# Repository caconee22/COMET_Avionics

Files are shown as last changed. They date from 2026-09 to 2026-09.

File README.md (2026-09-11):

# COMET_Avionics

COMET rocket avionics hardware project archive.

This repository replaces the previous `COMET_ROK_2` repository with the full
COMET avionics workspace layout.

## Structure

- `ROK2025/`: ROK2-era module board and reference files.
- `ROK2026/`: Current ROK2026 KiCad projects, shared libraries, and revisions.
- `ROK2026/ROK_3/`: ROK3 small-form-factor and SMD-chip test board.
- `ROK2026/ROK_4/`: ROK4 power-design research test board.
- `ROK2026/Away_1/`: Current active avionics candidate version under development.

## Project History

- `ROK2025/COMET_ROK_2`: First ROK2 circuit and module board. It was not used
  because of software development staffing issues.
- `ROK2026/ROK_3`: Miniaturized ROK3 version with SMD chips. It was not used
  because of power-section issues, but it may still be recoverable and remains
  a test version.
- `ROK2026/ROK_4`: A further test version focused on power-section design. It
  is a research version for a small buck-converter power design.
- `ROK2026/Away_1`: The avionics version candidate intended for actual use. It
  is currently under development.

## Avionics Design Intent

This design intent applies to the whole COMET avionics board family.

## 설계 목적

COMET_Avionics의 목적은 단순한 데이터 로거가 아니라, 로켓 비행 중 필요한
항공전자 기능을 안정적으로 수행하는 것이다.

가장 중요한 기능은 최고점 판단, 지연 사출 판단, 그리고 실제 사출 작동이다.
로그 저장, 통신, GPS 전송, LED, 부저, 콘솔 출력은 모두 보조 기능이며,
이 기능들이 사출 판단과 작동을 막아서는 안 된다.

## 우선순위 규약

1. 사출 판단과 사출 작동을 최우선으로 둔다.
2. SD카드 기록, LoRa, MQTT, Wi-Fi/LTE, GPS 텔레메트리, LED, 부저, 콘솔은
   사출 경로를 블로킹하지 않아야 한다.
3. 센서 감시는 100Hz 이상을 기본 목표로 한다.
4. 저장과 통신은 큐나 별도 작업으로 분리해 지연이 생겨도 비행 판단에 영향을
   주지 않게 한다.
5. 실제 비행 적용 전에는 회로, 펌웨어, 전원부, 사출부를 별도로 검증해야 한다.

## 센서와 비행 판단

기본 설계 방향은 압력 센서, IMU, 배터리 전압, 사출 감지, GPS 최신값을 함께
다루는 것이다.

`Away_1`의 메인 IMU는 STMicroelectronics `LSM6DSO32XTR`를 채택한다.
이 센서는 3축 가속도, 3축 자이로, 온도 센서를 포함하며, 가속도는 최대
±32g, 자이로는 최대 ±2000dps 범위를 기준으로 사용할 수 있다.

비행 중에는 발사 감지, 최고점 판단, 지연 사출, 착지 판단, 회수 모드 진입을
이벤트로 남긴다. 고도, 필터링된 속도, 가속도 크기, 발사/최고점 판단 점수,
GPS 속도와 방향처럼 후처리가 가능한 값은 가능한 한 뷰어나 분석 도구에서
계산한다.

## 어포지 판단 예비 기준

어포지 판단은 센서 하나만으로 결정하지 않고, 기압 고도, IMU 상태, 시간 조건을
함께 보는 상태머신으로 구성한다. 초기 로켓은 발사 실패, 중간 고도 이후 뒤집힘,
상하 반전, 과격한 회전, 불안정 비행이 생길 수 있으므로 정상 비행만 가정하지
않는다.

기본 상태 흐름은 다음을 기준으로 한다.

1. `PAD`: 발사 전 대기 상태.
2. `LAUNCHED`: 발사 감지 후 상승 시작 상태.
3. `COAST_NORMAL`: 정상 상승/관성 비행으로 판단되는 상태.
4. `UNSTABLE_FLIGHT`: 뒤집힘, 과격한 회전, 고도 상승 이상 등 비정상 비행 상태.
5. `APOGEE_DETECTED`: 어포지 또는 하강 시작이 확인된 상태.
6. `FAILSAFE_DEPLOY`: 센서 이상이나 비정상 비행으로 백업 사출이 필요한 상태.
7. `RECOVERY`: 사출 이후 회수 상태.

정상 어포지 판단은 다음 조건을 함께 본다.

- 발사 감지가 완료되어 있을 것.
- 발사 후 최소 사출 금지 시간이 지났을 것.
- 필터링된 기압 고도 기준 최고 고도를 추적할 것.
- 현재 고도가 최고 고도보다 일정량 이상 낮아질 것.
- 필터링된 수직 속도가 음수 방향일 것.
- 위 조건이 짧은 시간 동안 지속될 것.

초기 기준값은 다음 범위에서 시험하며 조정한다.

- 최소 사출 금지 시간: 발사 후 1~2초.
- 고도 하락 판단: 최고 고도 대비 2~5m 하락.
- 하강 지속 시간: 200~500ms.
- 백업 사출 시간: 예상 어포지 이후를 기준으로 별도 시험값 설정.

비정상 비행 판단은 다음 상황을 감지하는 방향으로 둔다.

- 자이로 회전율이 일정 시간 이상 매우 큰 상태.
- 가속도 방향이 계속 급격하게 바뀌는 상태.
- 발사 후 고도 상승이 거의 없거나 예상보다 빨리 멈추는 상태.
- 고도 상승 후 불규칙한 정체와 하락이 반복되는 상태.
- IMU 축 기준 위아래 판단이 신뢰하기 어려운 상태.

비정상 비행 상태에서는 IMU 적분 고도나 자세 기준 판단에 의존하지 않는다.
기압 고도 변화, 시간 조건, 회전 이상 감지를 우선 사용하고, 필요하면 정상
어포지보다 보수적인 백업 사출 조건으로 전환한다.

개념적인 판단식은 다음과 같다.

```text
if launched and time_since_launch > min_deploy_time:
    if altitude_peak - altitude_filtered > altitude_drop_threshold
       and vertical_velocity_filtered < 0
       and falling_duration > falling_hold_time:
        apogee_detected = true

    if unstable_flight and altitude_not_increasing:
        failsafe_deploy = true

    if time_since_launch > max_flight_time:
        failsafe_deploy = true
```

이 기준은 비행 검증 완료값이 아니라 초기 개발용 예비 기준이다. 실제 임계값은
기체 질량, 모터 추력 곡선, 벤트홀 설계, 지상 시험, 저고도 시험 결과를 보고
조정한다.

## 로그 규약

로그는 텍스트보다 바이너리 형식을 우선한다.

- `LOG`: 고정 길이 센서 샘플
- `EVENT`: 발사, 최고점, 사출, 착지, 전압 변화, SD 오류, 파일 회전, 통신 상태,
  GPS fix/loss, 회수 모드 진입 같은 이벤트 기록

`LOG`에는 시간 코드, 시퀀스 번호, 상태 플래그, 압력, 온도, IMU 가속도/자이로,
최신 GPS 위도/경도/고도, GPS 플래그, 배터리 전압, 사출 센서 상태 같은
raw/minimal 값을 저장하는 방향으로 둔다.

## 로그 동작 흐름

패드 대기 또는 armed 상태에서는 최근 약 3초 분량의 100Hz RAM prebuffer를
유지한다. 평상시 저장은 10Hz 정도로 제한할 수 있다.

발사가 감지되면 발사 직전 prebuffer와 발사 이후 데이터를 100Hz로 저장한다.
최고점/사출 이후 하강 구간은 짧은 시간 단위 파일로 분리하는 방향을 둔다.

착지가 10초 이상 안정적으로 확인되면 고속 로그를 닫고, 회수/저전력 모드로
전환한다. 이 상태에서는 1Hz 수준으로 로그를 줄이고 GPS 위치를 LoRa와 MQTT로
전송하는 것을 목표로 한다.

## 통신과 회수

LoRa 433MHz는 지상국과 회수용 통신을 위한 기본 방향으로 둔다.
MQTT는 온보드 Wi-Fi/LTE 라우터를 통한 원격 모니터링 또는 회수 보조 용도로
사용할 수 있다.

통신 실패는 비행 판단 실패로 이어지면 안 된다. 통신은 가능한 경우 보내고,
안 되는 경우에는 로그와 사출 판단이 계속 살아 있어야 한다.

## 검증 기준

이 문서는 COMET_Avionics 전체 보드에 적용되는 설계 의도와 개발 규약이다.
각 보드는 실제 비행 적용 전 회로, 펌웨어, 전원부, 사출부를 별도로 검증해야
하며, README에 적힌 내용만으로 비행 검증 완료를 의미하지 않는다.

Temporary extraction/work folders such as `tmp/` and `tmp_pdf_kmg/` are not
tracked.

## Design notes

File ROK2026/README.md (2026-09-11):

# ROK2026

COMET ROK 2026 hardware project workspace.

## Projects

- `ROK_3`: Miniaturized ROK3 SMD-chip test board.
- `ROK_4`: ROK4 power-section design and small buck-converter research board.
- `Away_1`: Active avionics candidate version under development.

## Board Status

- `ROK_3`: Small-form-factor version using SMD chips. It was not used because
  of power-section issues, but it may still be recoverable and remains a test
  version.
- `ROK_4`: Further test version for power-section design. It is a research
  board for the small buck-converter power design.
- `Away_1`: The candidate avionics version intended for actual use. This is the
  current development target.

## Away_1

`Away_1` is the active candidate for the real avionics version.
It is currently under development.

The avionics design intent and development rules apply to the whole board
family and are documented in the root `README.md`.

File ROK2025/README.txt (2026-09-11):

ROKv2.xlsx 에 모든 설명이 있으며 두 시트를 참조하시오
ROK2.zip 파일이 PCB 의 데이터 원본 파일이며 KICAD 로 편집할수있습니다
GB.zip 에 거버파일이 있으며 이를 이요해 같은 PCB 를 생산할수있습니다
C3_ROK2.zip 의 테스트를 위해 구동하던 약간의 예제 코드가 있으며 이는 구동을 위한것이아닌 개발환경 예시를 위함입니다 코딩은 직접 해야합니다
C3_ROK.step 은 모델 파일이며 설개참조를 위해 있습니다

2026/01/20 스마트융합공학과 융합로봇전공 이학현
lhh060508@gmail.com / 010-5034-6220
작성자는 나라를 지키러 갑니다

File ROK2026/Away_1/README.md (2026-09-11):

# Away_1

`Away_1` is the active candidate for the real COMET avionics version.
It is currently under development.

This board inherits the core avionics/logger intent from the earlier ROK2
concept, but it is treated as the current development target rather than a
completed flight-validated design.

The avionics design intent and development rules apply to the whole
COMET_Avionics board family and are documented in the root `README.md`.

## 전원 구성

`Away_1`은 배터리 2개를 사용하는 전원 구조를 기준으로 개발한다.

- 로거용 배터리
- 대전류 구동용 배터리

두 배터리는 모두 2~3S LiPo를 기준으로 하며, 용량은 약 500mAh급을 상정한다.

## 로거용 전원

로거용 배터리는 비행 판단, 기록, 통신 계통을 담당한다.

주요 공급 대상은 다음과 같다.

- ESP
- 내부 센서
- LoRa
- GPS
- LTE 모듈용 5V 2A 전원

로거용 전원은 센서 감시, 로그 기록, 위치 송신, 지상국 통신이 유지되도록 하는
쪽을 우선한다. 대전류 부하의 순간 전류나 노이즈가 로거 계통을 불안정하게
만들지 않도록 분리하는 것을 기본 방향으로 둔다.

## 대전류 구동용 전원

대전류 구동용 배터리는 직접 구동 부하를 담당한다.

주요 공급 대상은 다음과 같다.

- 30kg급 서보 2개
- 니크롬 코일 점화기

이 전원 계통은 서보 구동과 점화기 동작처럼 순간 전류가 큰 부하를 처리하기
위한 것이다. 로거용 전원과 역할을 분리해, 구동 부하가 동작할 때도 ESP와 센서,
통신 장치가 가능한 한 안정적으로 유지되도록 한다.

## 메인 IMU

`Away_1`의 메인 IMU는 STMicroelectronics `LSM6DSO32XTR`를 채택한다.

이 부품은 3축 가속도, 3축 자이로, 온도 센서를 포함하는 6축 IMU이며, ESP와는
I2C 또는 SPI로 연결할 수 있다. 비행 로그와 자세/회전 측정에는 SPI 연결을
우선 검토한다.

기본 운용 목표는 다음과 같다.

- 가속도 범위: ±32g
- 자이로 범위: ±2000dps
- 가속도 민감도: 0.976mg/LSB at ±32g
- 자이로 민감도: 70mdps/LSB at ±2000dps
- 전원 범위: 1.71V~3.6V
- 패키지: LGA-14

`LSM6DSO32XTR`는 MPU6500이나 ICM-42688-P의 ±16g 범위보다 넓은 ±32g
가속도 범위를 제공하므로, `Away_1`의 메인 IMU로 사용한다. 다만 점화 충격,
사출 충격, 착지 충격처럼 ±32g를 넘을 수 있는 이벤트까지 모두 보장하는
고G 전용 센서는 아니므로, 필요하면 별도 고G 가속도센서를 보조로 검토한다.

## 어포지 판단

`Away_1`의 어포지 판단은 루트 `README.md`의 어포지 판단 예비 기준을 따른다.
정상 상승만 가정하지 않고, 발사 실패나 중간 고도 이후 뒤집힘, 과격한 회전,
불안정 비행 가능성을 함께 고려한다.

## 개발 상태

`Away_1`은 실제 사용을 목표로 하는 에비오닉스 후보 버전이지만, 아직 개발 중인
보드다. 전체 설계 의도 규약은 루트 `README.md`를 기준으로 한다.

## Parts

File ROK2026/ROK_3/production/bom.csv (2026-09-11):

Designator | Footprint | Quantity | Value | LCSC Part #
A1 | YD-ESP32-S3 | 1 | YD-ESP32-S3
BT1 | S8411-45R_1 | 1 | CR1220 | C70381
C1, C2 | 0805 | 2 | 22uF
C10, C9 | CP_Elec_6.3x5.3 | 2 | 100uF
C11, C13, C15 | 0805 | 3 | 0.1uF | C14663
C12 | 0805 | 1 | 10nF | C57112
C14, C5, C6 | 0805 | 3 | 0.1uF
C16, C3, C4 | 0805 | 3 | 10uF
C17 | 0805 | 1 | 1uF
C7, C8 | 0805 | 2 | 47pF
D1 | LED_WS2812B_PLCC4_5.0x5.0mm_P3.2mm | 1 | WS2812B
J1, J7 | AMASS_XT30U-F_1x02_P5.0mm_Vertical | 2 | 5267-02A
J2 | Molex_SPOX_5267-02A_1x02_P2.50mm_Vertical | 1 | 5267-02A
J3, J5 | Molex_SPOX_5267-03A_1x03_P2.50mm_Vertical | 2 | Conn_01x03
J4, J8 | Molex_SPOX_5267-04A_1x04_P2.50mm_Vertical | 2 | Conn_01x04
J6 | TerminalBlock_4Ucon_1x02_P3.50mm_Horizontal | 1 | 5267-02A
J9 | HRS_DM3D-SF | 1 | DM3D-SF
L1, L2 | L_Sumida_CDMC6D28_7.25x6.5mm | 2 | 6.8uH
Q1 | TO-220-3_Horizontal_TabDown | 1 | IRLB8721PBF
R1, R3 | 0805 | 2 | 158K
R10, R11, R12, R13, R5, R6, R8, R9 | 0805 | 8 | 10k | C25804
R14 | 0805 | 1 | 22 | C25804
R15, R16 | 0805 | 2 | 100 | C25804
R2, R4 | 0805 | 2 | 30.1K
R7 | 0805 | 1 | 220
SW1 | SW_PUSH_6mm_H5mm | 1 | SW_Push
U1, U2 | TSOT-23-6 | 2 | AP63300QWU
U3 | SOT-223-3_TabPin2 | 1 | AMS1117-3.3
U4 | LGA-8_3x5mm_P1.25mm | 1 | MS5611-01BA
U5 | QFN-24-1EP_3x3mm_P0.4mm_EP1.75x1.6mm | 1 | MPU-6500 | C50278
U6 | SOIC-16W_7.5x10.3mm_P1.27mm | 1 | DS3231M
U7 | VISHAY_VCNL4040_4X2X1.1 | 1 | VCNL4040M3OE

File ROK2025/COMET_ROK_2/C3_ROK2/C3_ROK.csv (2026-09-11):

Reference | Qty | Value | DNP | Exclude from BOM | Exclude from Board | Footprint | Datasheet
BZ1 | 1 | Buzzer |  |  |  | Buzzer_Beeper:Buzzer_12x9.5RM7.6 | ~
C1,C2,C3,C6 | 4 | 0.1uF |  |  |  | Capacitor_SMD:C_0805_2012Metric_Pad1.18x1.45mm_HandSolder | ~
C4 | 1 | 10uF |  |  |  | Capacitor_THT:CP_Radial_D6.3mm_P2.50mm
C5 | 1 | 10uF |  |  |  | Capacitor_THT:CP_Radial_D5.0mm_P2.00mm
C7 | 1 | 22uF |  |  |  | Capacitor_THT:CP_Radial_D5.0mm_P2.00mm
D1 | 1 | LED_RGB |  |  |  | LED_SMD:LED_RGB_5050-6 | ~
H1,H2,H3,H4 | 4 | MountingHole_Pad |  | BOM에서 제외됨 |  | MountingHole:MountingHole_3.2mm_M3_DIN965_Pad | ~
J1 | 1 | 5267-04A |  |  |  | Connector_Molex:Molex_SPOX_5267-04A_1x04_P2.50mm_Vertical | ~
J2 | 1 | 5267-02A |  |  |  | Connector_Molex:Molex_SPOX_5267-02A_1x02_P2.50mm_Vertical | ~
J3 | 1 | 5267-06A |  |  |  | Connector_Molex:Molex_SPOX_5267-06A_1x06_P2.50mm_Vertical | ~
J4 | 1 | Conn_01x03 |  |  |  | Connector_Molex:Molex_SPOX_5267-03A_1x03_P2.50mm_Vertical | ~
Q1 | 1 | IRLML2402TR |  |  |  | Package_TO_SOT_SMD:SOT-23_Handsoldering
R1 | 1 | 10k |  |  |  | Resistor_SMD:R_0805_2012Metric_Pad1.20x1.40mm_HandSolder | ~
R2,R3,R4,R5,R6,R9,R10,R11,R12,R13 | 10 | 0 |  |  |  | Resistor_SMD:R_0805_2012Metric_Pad1.20x1.40mm_HandSolder | ~
R7 | 1 | 100 |  |  |  | Resistor_SMD:R_0805_2012Metric_Pad1.20x1.40mm_HandSolder | ~
R8 | 1 | 47k |  |  |  | Resistor_SMD:R_0805_2012Metric_Pad1.20x1.40mm_HandSolder | ~
SW1 | 1 | SW_Push |  |  |  | Button_Switch_THT:SW_PUSH_6mm_H5mm | ~
U1 | 1 | L7805 |  |  |  | Package_TO_SOT_THT:TO-220-3_Horizontal_TabDown | http://www.st.com/content/ccc/resource/technical/document/datasheet/41/4f/b3/b0/12/d4/47/88/CD00000444.pdf/files/CD00000444.pdf/jcr:content/translations/en.CD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
U2 | 1 | AMS1117-3.3 |  |  |  | Package_TO_SOT_SMD:SOT-223-3_TabPin2 | http://www.advanced-monolithic.com/pdf/ds1117.pdf
U3 | 1 | ESP32-C3_SUPERMINI_TH |  |  |  | esp c3:MODULE_ESP32-C3_SUPERMINI_TH
U4 | 1 | ~ |  |  |  | Library:ds3231
U5 | 1 | ~ |  |  |  | Library:BMP280
U6 | 1 | ~ |  |  |  | Library:MPU6050

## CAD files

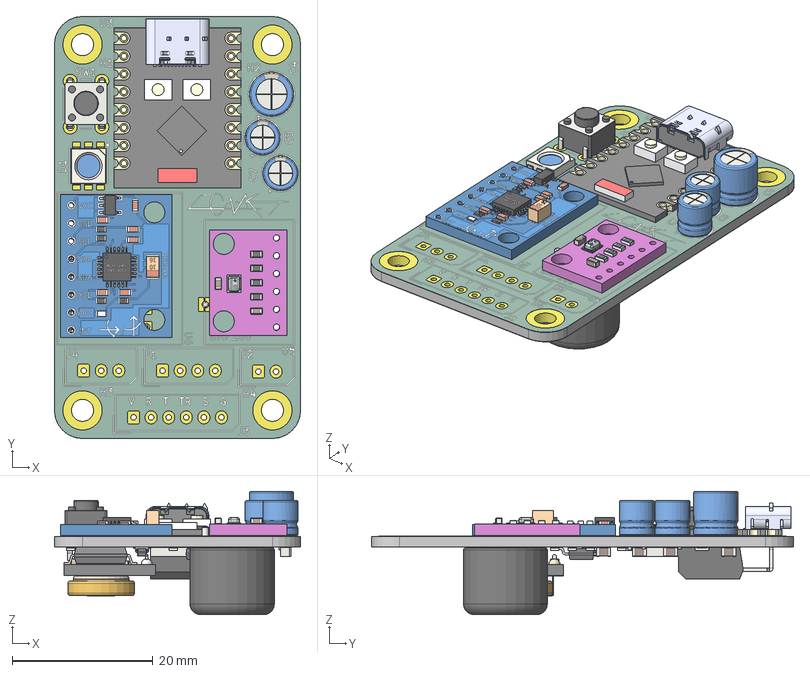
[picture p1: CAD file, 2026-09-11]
ROK2025/COMET_ROK_2/C3_ROK.step
35.0 x 60.0 x 17.5 mm
CP_Radial_D5.0mm_P2.00mm x 2
bmp280_module
Board c3mini
USB C
components (other)^ESP32-C3 SuperMini
MPU6050
SW_PUSH_6mm_H5mm
CP_Radial_D6.3mm_P2.50mm
LED_RGB_5050-6
Board_001
5 Pos Socket Header_001
SOIC16_001
0805 Resistor_001
0805 Resistor_002
0805 Capacitor_001
Battery_001
R_0805_2012Metric x 13
C_0805_2012Metric x 4
SOT-223
Buzzer_12x9.5RM7.6
TO-220-3_Horizontal_TabDown
SOT-23
C3_ROK_copper
C3_ROK_silkscreen
C3_ROK_soldermask
C3_ROK_PCB

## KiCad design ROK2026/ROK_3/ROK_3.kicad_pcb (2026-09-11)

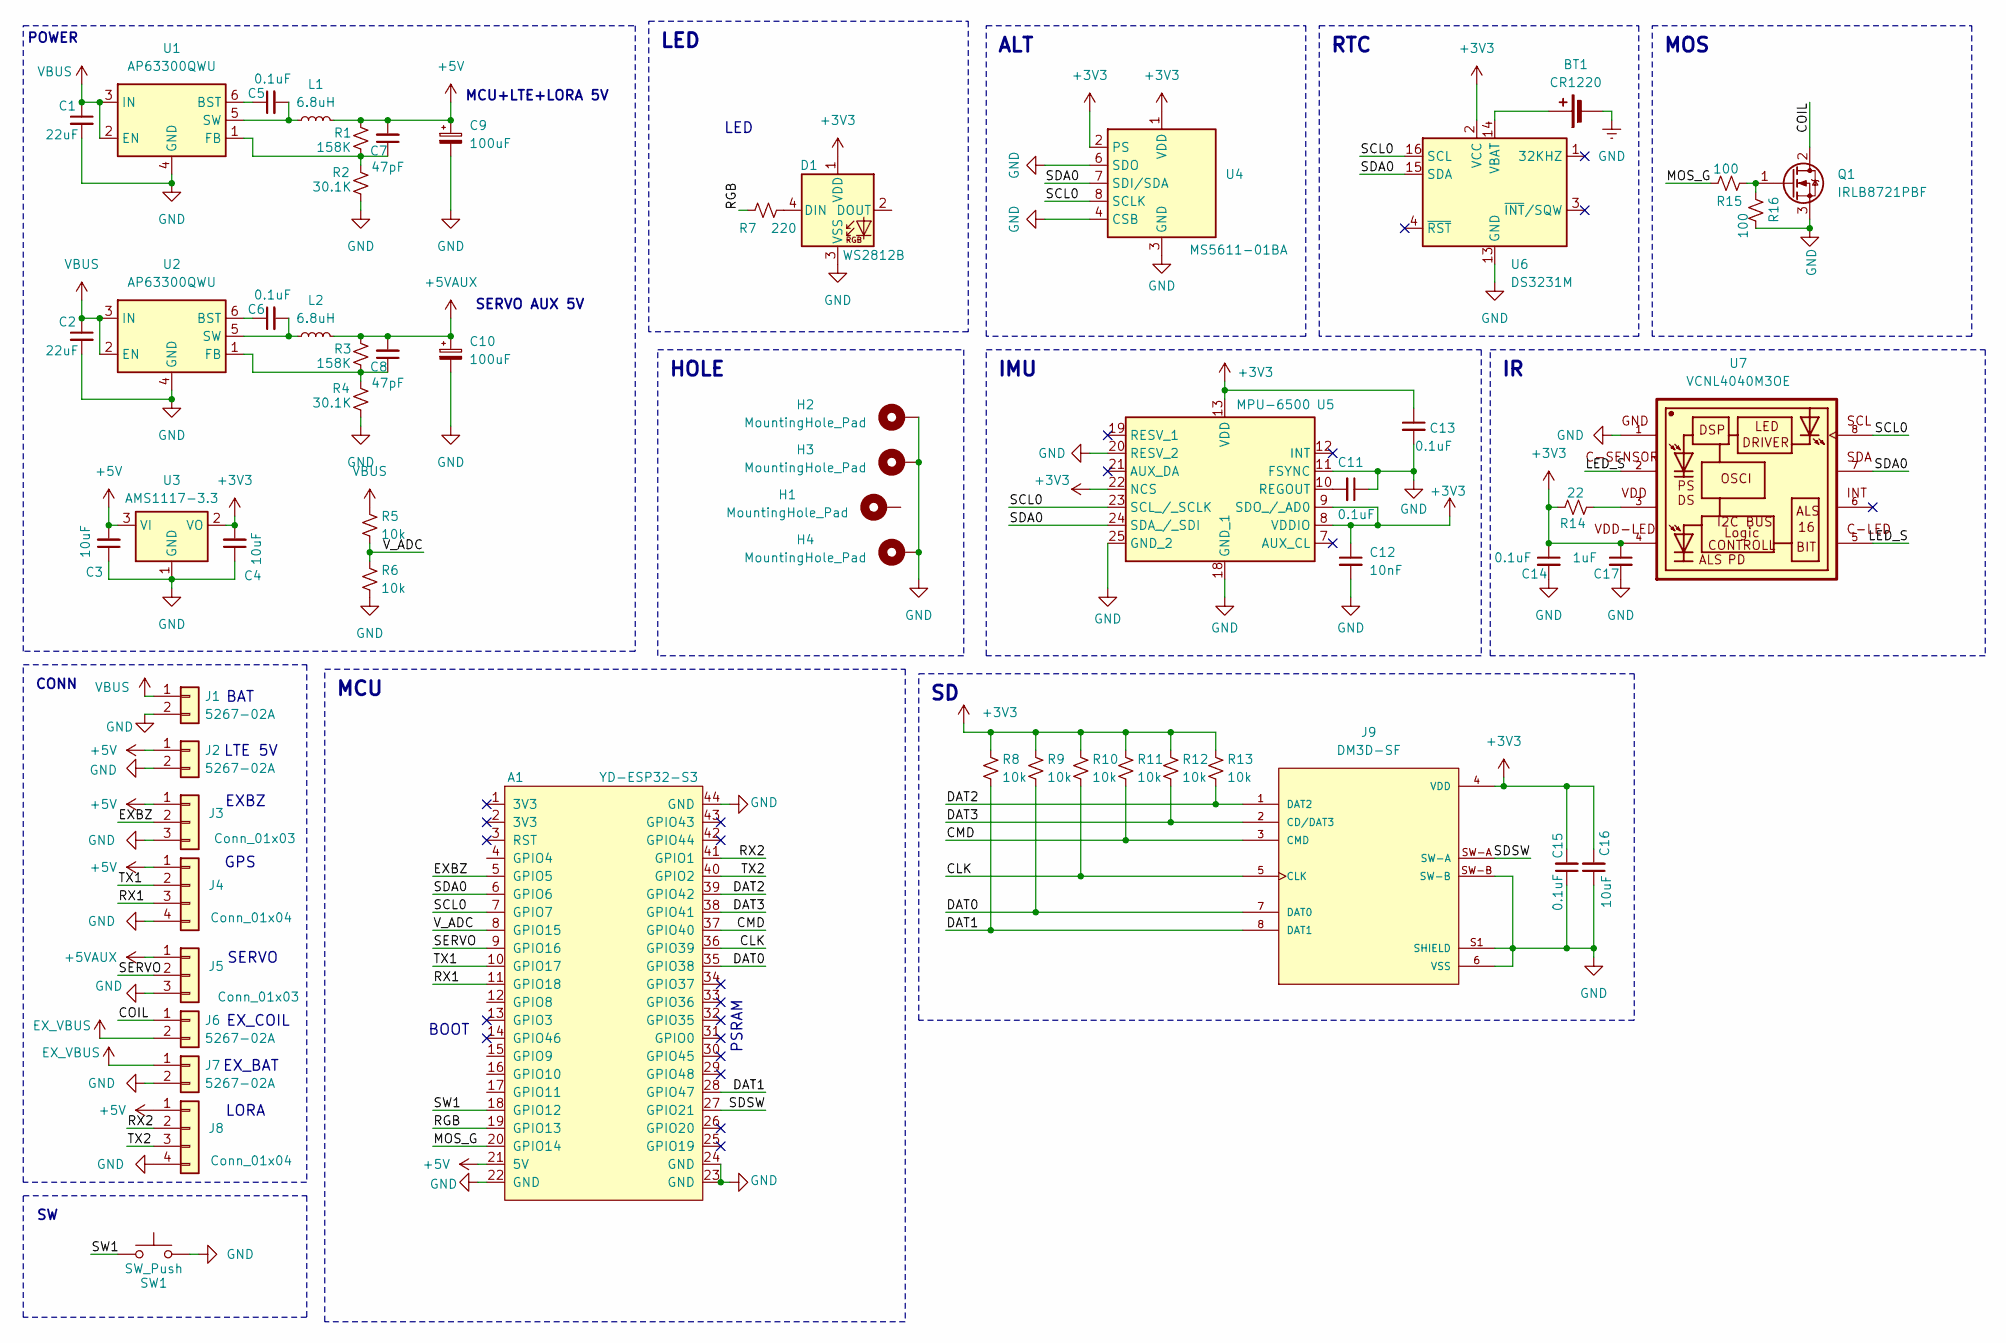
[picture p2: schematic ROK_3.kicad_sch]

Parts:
A1: YD-ESP32-S3
BT1: CR1220; S8411-45R_1; Manufacturer_Part_Number CR1220-2; LCSC C70381
C1, C2: 22uF; C_0805_2012Metric
C3, C4, C16: 10uF; C_0805_2012Metric
C5, C6, C14: 0.1uF; C_0805_2012Metric
C7, C8: 47pF; C_0805_2012Metric
C9, C10: 100uF; CP_Elec_6.3x5.3
C11, C13: 0.1uF; C_0805_2012Metric; LCSC C14663
C12: 10nF; C_0805_2012Metric; LCSC C57112
C15: 0.1uF; C_0805_2012Metric; Manufacturer_Part_Number CC0603KRX7R9BB104; LCSC C14663
C17: 1uF; C_0805_2012Metric
D1: WS2812B; LED_WS2812B_PLCC4_5.0x5.0mm_P3.2mm
H1, H2, H3, H4: MountingHole_Pad; MountingHole_3.2mm_M3_DIN965_Pad
J1, J7: 5267-02A; AMASS_XT30U-F_1x02_P5.0mm_Vertical
J2: 5267-02A; Molex_SPOX_5267-02A_1x02_P2.50mm_Vertical
J3, J5: Conn_01x03; Molex_SPOX_5267-03A_1x03_P2.50mm_Vertical
J4, J8: Conn_01x04; Molex_SPOX_5267-04A_1x04_P2.50mm_Vertical
J6: 5267-02A; TerminalBlock_4Ucon_1x02_P3.50mm_Horizontal
J9: DM3D-SF; HRS_DM3D-SF; PARTREV 2017.1
L1, L2: 6.8uH; L_Sumida_CDMC6D28_7.25x6.5mm
Q1: IRLB8721PBF; TO-220-3_Horizontal_TabDown
R1, R3: 158K; R_0805_2012Metric
R2, R4: 30.1K; R_0805_2012Metric
R5, R6, R8, R9, R10, R11, R12, R13: 10k; R_0805_2012Metric; LCSC C25804
R7: 220; R_0805_2012Metric_Pad1.20x1.40mm_HandSolder
R14: 22; R_0805_2012Metric; LCSC C25804
R15, R16: 100; R_0805_2012Metric; LCSC C25804
SW1: SW_Push; SW_PUSH_6mm_H5mm
U1, U2: AP63300QWU; TSOT-23-6
U3: AMS1117-3.3; SOT-223-3_TabPin2
U4: MS5611-01BA; LGA-8_3x5mm_P1.25mm
U5: MPU-6500; QFN-24-1EP_3x3mm_P0.4mm_EP1.75x1.6mm; Manufacturer_Part_Number MPU-6500; Mouser Part Number 410-MPU-6500
U6: DS3231M; SOIC-16W_7.5x10.3mm_P1.27mm
U7: VCNL4040M3OE; VISHAY_VCNL4040_4X2X1.1

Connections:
+3V3: C4.2, C12.1, C13.1, C14.1, C15.2, C16.2, C17.1, D1.1 (VDD), J9.4 (VDD), R8.2, R9.2, R10.2, R11.2, R12.2, R13.2, R14.2, U3.2 (VO), U4.1 (VDD), U4.2 (PS), U5.8 (VDDIO), U5.9 (SDO_/_AD0), U5.13 (VDD), U5.22 (NCS), U6.2 (VCC), U7.4
+5V: A1.21 (5V), C3.2, C7.2, C9.1, J2.1, J3.1, J4.1, J8.1, L1.2, R1.1, U3.3 (VI)
+5VAUX: C8.2, C10.1, J5.1, L2.2, R3.1
/CLK: A1.36 (GPIO39), J9.5 (CLK), R10.1
/CMD: A1.37 (GPIO40), J9.3 (CMD), R11.1
/COIL: J6.1, Q1.2 (D)
/DAT0: A1.35 (GPIO38), J9.7 (DAT0), R9.1
/DAT1: A1.28 (GPIO47), J9.8 (DAT1), R8.1
/DAT2: A1.39 (GPIO42), J9.1 (DAT2), R13.1
/DAT3: A1.38 (GPIO41), J9.2 (CD/DAT3), R12.1
/EXBZ: A1.5 (GPIO5), J3.2
/LED_S: U7.2, U7.5
/MOS_G: A1.20 (GPIO14), R15.2
/RGB: A1.19 (GPIO13), R7.2
/RX1: A1.11 (GPIO18), J4.3
/RX2: A1.41 (GPIO1), J8.2
/SCL0: A1.7 (GPIO7), U4.8 (SCLK), U5.23 (SCL_/_SCLK), U6.16 (SCL), U7.8
/SDA0: A1.6 (GPIO6), U4.7 (SDI/SDA), U5.24 (SDA_/_SDI), U6.15 (SDA), U7.7
/SDSW: A1.27 (GPIO21), J9.SW-A
/SERVO: A1.9 (GPIO16), J5.2
/SW1: A1.18 (GPIO12), SW1.1
/TX1: A1.10 (GPIO17), J4.2
/TX2: A1.40 (GPIO2), J8.3
/V_ADC: A1.8 (GPIO15), R5.1, R6.2
EX_VBUS: J6.2, J7.1
GND: A1.22 (GND), A1.23 (GND), A1.24 (GND), A1.44 (GND), BT1.2 (-), C1.2, C2.2, C3.1, C4.1, C9.2, C10.2, C11.1, C12.2, C13.2, C14.2, C15.1, C16.1, C17.2, D1.3 (VSS), H2.1 (1_1), H3.1 (1_1), H4.1 (1_1), J1.2, J2.2, J3.3, J4.4, J5.3, J7.2, J8.4, J9.6 (VSS), J9.S1 (SHIELD), J9.S2 (SHIELD), J9.S3 (SHIELD), J9.S4 (SHIELD), J9.SW-B, Q1.3 (S), R2.1, R4.1, R6.1, R16.2, SW1.2, U1.4 (GND), U2.4 (GND), U3.1 (GND), U4.3 (GND), U4.4 (CSB), U4.5 (CSB), U4.6 (SDO), U5.11 (FSYNC), U5.18 (GND_1), U5.20 (RESV_2), U5.25 (GND_2), U6.5 (GND), U6.6 (GND), U6.7 (GND), U6.8 (GND), U6.9 (GND), U6.10 (GND), U6.11 (GND), U6.12 (GND), U6.13 (GND), U7.1
unnamed: BT1.1 (+), U6.14 (VBAT)
unnamed: D1.4 (DIN), R7.1
unnamed: Q1.1 (G), R15.1, R16.1
unnamed: R14.1, U7.3
unnamed: C5.1, U1.6 (BST)
unnamed: C7.1, R1.2, R2.2, U1.1 (FB)
unnamed: C5.2, L1.1, U1.5 (SW)
unnamed: C6.1, U2.6 (BST)
unnamed: C8.1, R3.2, R4.2, U2.1 (FB)
unnamed: C6.2, L2.1, U2.5 (SW)
unnamed: C11.2, U5.10 (REGOUT)
VBUS: C1.1, C2.1, J1.1, R5.2, U1.2 (EN), U1.3 (IN), U2.2 (EN), U2.3 (IN)

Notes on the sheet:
EXBZ
EX_BAT
GPS
POWER
EX_COIL
BOOT
BAT
SERVO AUX 5V
PSRAM
MCU+LTE+LORA 5V
LED
LTE 5V
LORA
CONN
SERVO
ALT
MOS
IMU
MCU
RTC
HOLE

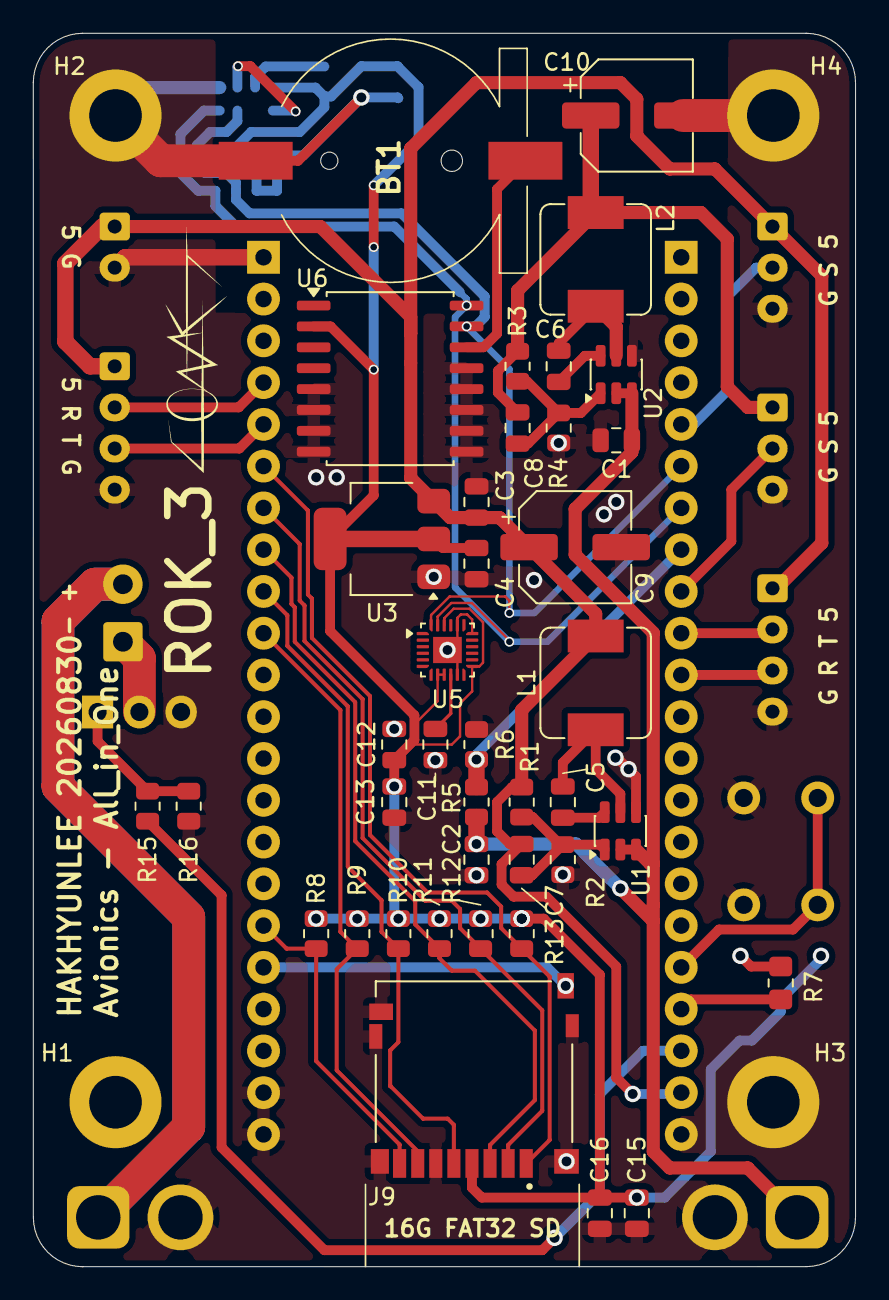
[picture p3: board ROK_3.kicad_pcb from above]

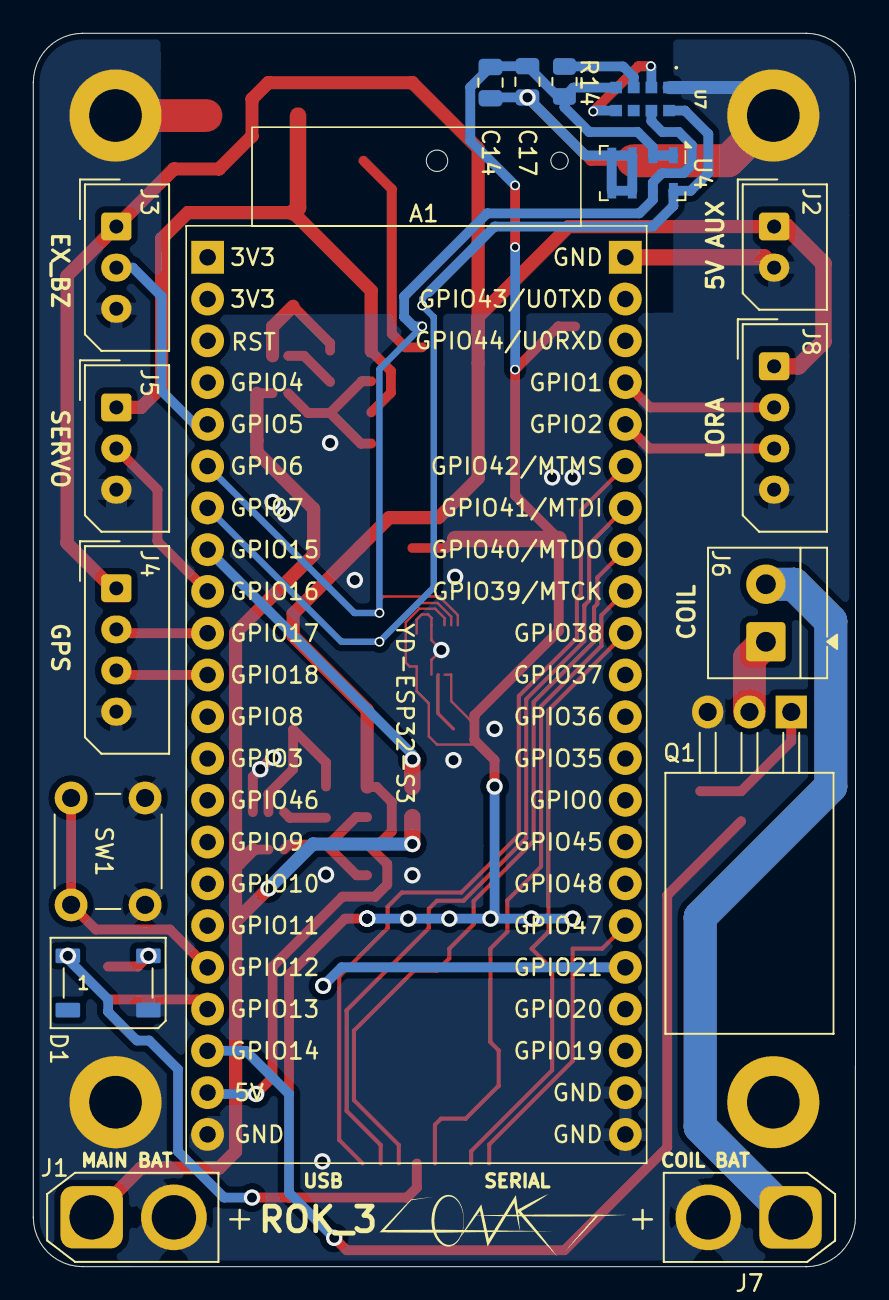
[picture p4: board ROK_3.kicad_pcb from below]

Board: 2 copper layers, 50.0 x 75.0 mm, 60 parts (17 on the bottom side), 38 nets.

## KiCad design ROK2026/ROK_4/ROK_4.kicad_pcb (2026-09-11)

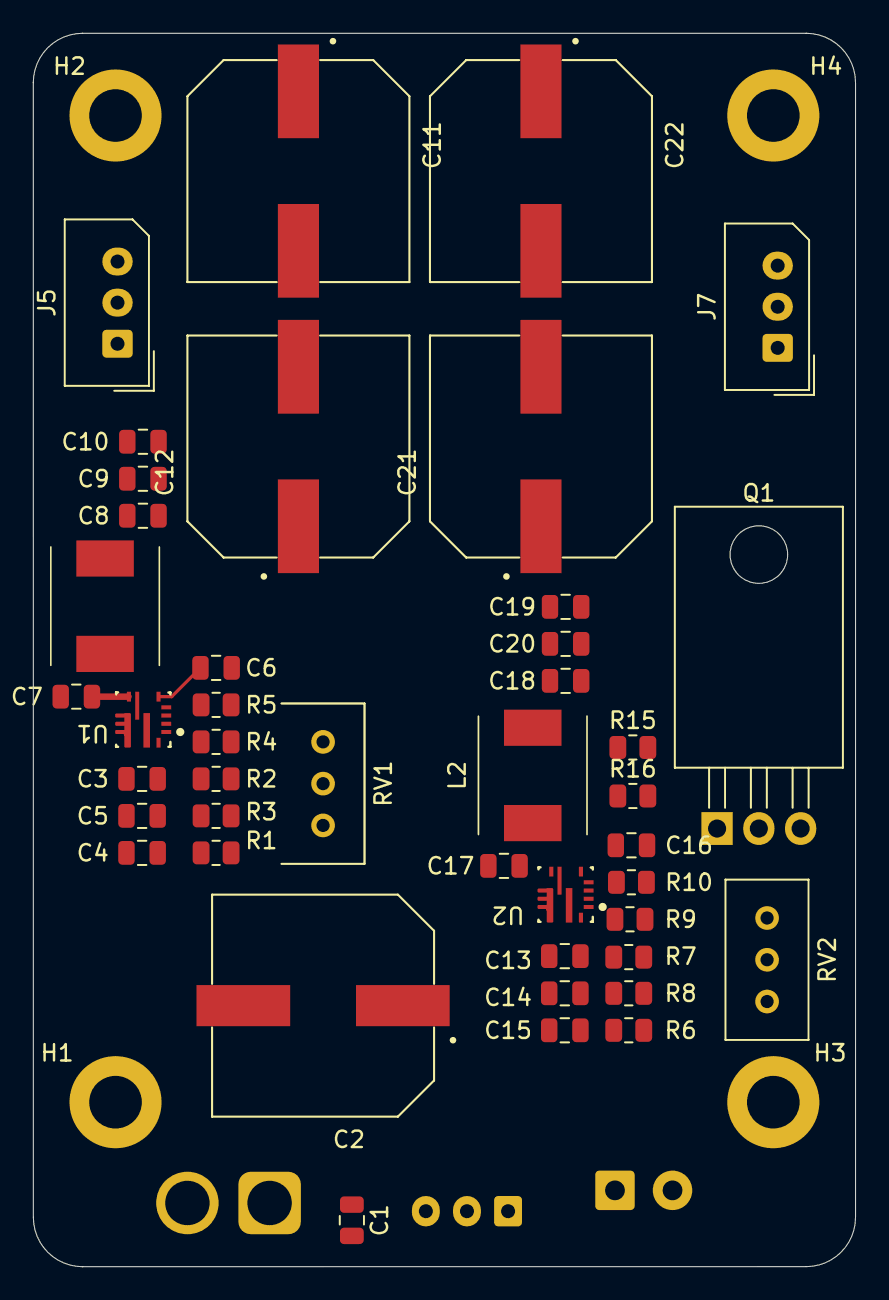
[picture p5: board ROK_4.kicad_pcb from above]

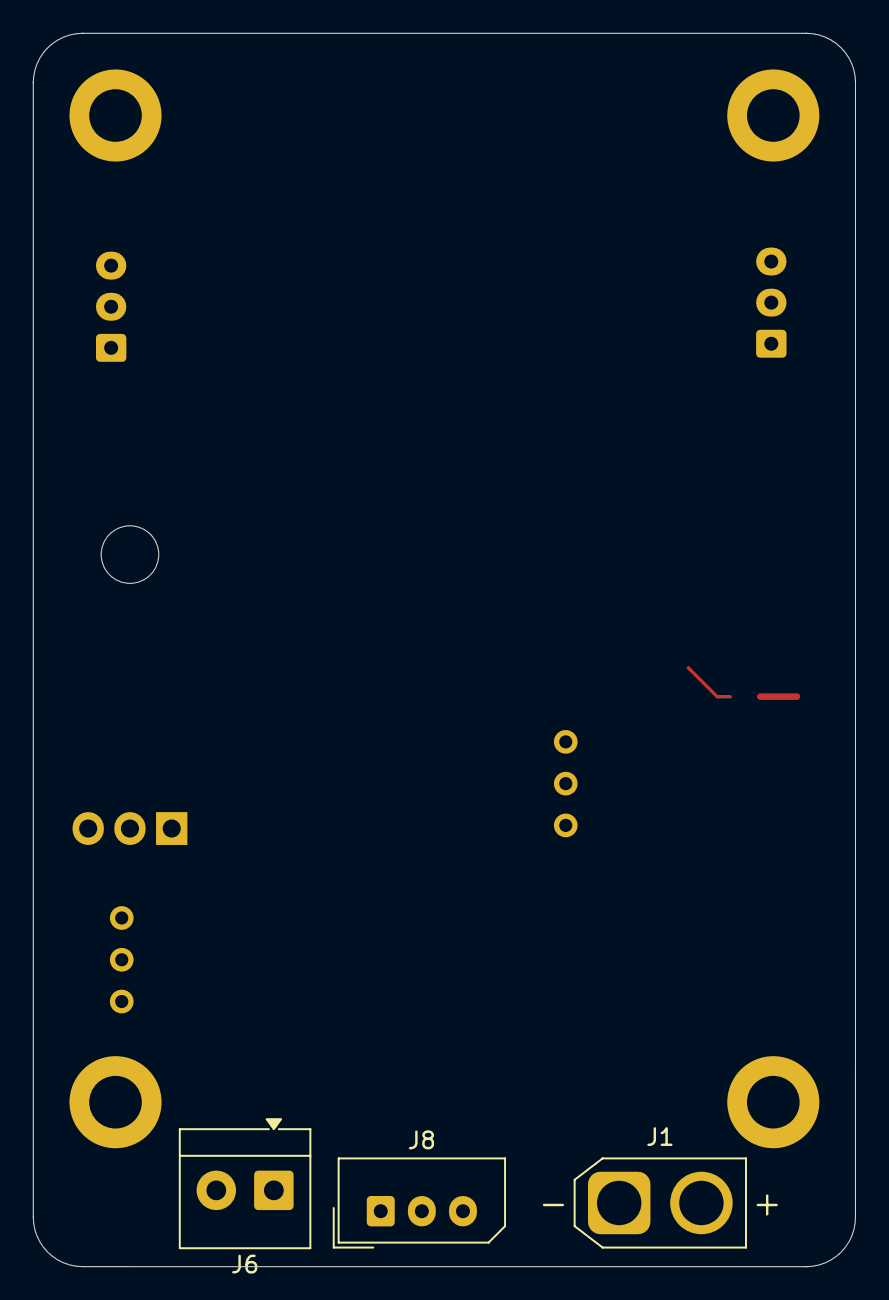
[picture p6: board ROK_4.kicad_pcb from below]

Board: 2 copper layers, 50.0 x 75.0 mm, 50 parts (3 on the bottom side), 19 nets.

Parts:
C1, C3, C7, C8, C13, C17, C18: 0.1uF; C_0805_2012Metric
C2, C11, C12, C21, C22: 1000uF; CAP_EEEFK1C182SQ
C4, C5, C9, C10, C14, C15, C19, C20: 10uF; C_0805_2012Metric
C6, C16: 100nF; C_0805_2012Metric
H1, H2, H3, H4: MountingHole_Pad; MountingHole_3.2mm_M3_DIN965_Pad
J1: Conn_01x02; AMASS_XT30U-M_1x02_P5.0mm_Vertical
J5, J7, J8: Conn_01x03; Molex_SPOX_5267-03A_1x03_P2.50mm_Vertical
J6: 5267-02A; TerminalBlock_4Ucon_1x02_P3.50mm_Horizontal
L1, L2: 4.7uH; L_Bourns_SRN6045TA
Q1: IRLB8721PBF; TO-220-3_Horizontal_TabDown
R1, R6: 52.3K; R_0805_2012Metric
R2, R7: 100K; R_0805_2012Metric
R3, R8: 47K; R_0805_2012Metric
R4, R9: 10K; R_0805_2012Metric
R5, R10: 62K; R_0805_2012Metric
R15, R16: 100; R_0805_2012Metric
RV1, RV2: 50K; Potentiometer_Bourns_3296W_Vertical
U1, U2: TPS56A37RPAR; TPS56A37RPAR_RPA0010A_VQFN-HR-10_3x3mm

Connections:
GND: C1.1, C2.2, C3.1, C4.1, C5.1, C6.1, C8.1, C9.1, C10.1, C11.2, C12.2, C13.1, C14.1, C15.1, C16.1, C18.1, C19.1, C20.1, C21.2, C22.2, H2.1 (1_1), H3.1 (1_1), H4.1 (1_1), J1.2, Q1.3 (S), R1.1, R3.2, R4.1, R6.1, R8.2, R9.1, R16.2, U1.3 (AGND), U1.9 (PGND), U2.3 (AGND), U2.9 (PGND)
unnamed: Q1.1 (G), R15.1, R16.1
unnamed: R5.1, RV1.3
unnamed: R10.1, RV2.3
unnamed: C7.2, U1.7 (BOOT)
unnamed: R2.2, R3.1, U1.1 (EN)
unnamed: R4.2, RV1.1, RV1.2, U1.2 (FB)
unnamed: R1.2, U1.10 (MODE)
unnamed: C6.2, U1.5 (SS)
unnamed: C7.1, L1.1, U1.6 (SW)
unnamed: C17.2, U2.7 (BOOT)
unnamed: R7.2, R8.1, U2.1 (EN)
unnamed: R9.2, RV2.1, RV2.2, U2.2 (FB)
unnamed: R6.2, U2.10 (MODE)
unnamed: C16.2, U2.5 (SS)
unnamed: C17.1, L2.1, U2.6 (SW)
SV1: C8.2, C9.2, C10.2, C11.1, C12.1, L1.2, R5.2
SV2: C18.2, C19.2, C20.2, C21.1, C22.1, L2.2, R10.2
VBUS: C1.2, C2.1, C3.2, C4.2, C5.2, C13.2, C14.2, C15.2, J1.1, R2.1, R7.1, U1.8 (VIN), U2.8 (VIN)

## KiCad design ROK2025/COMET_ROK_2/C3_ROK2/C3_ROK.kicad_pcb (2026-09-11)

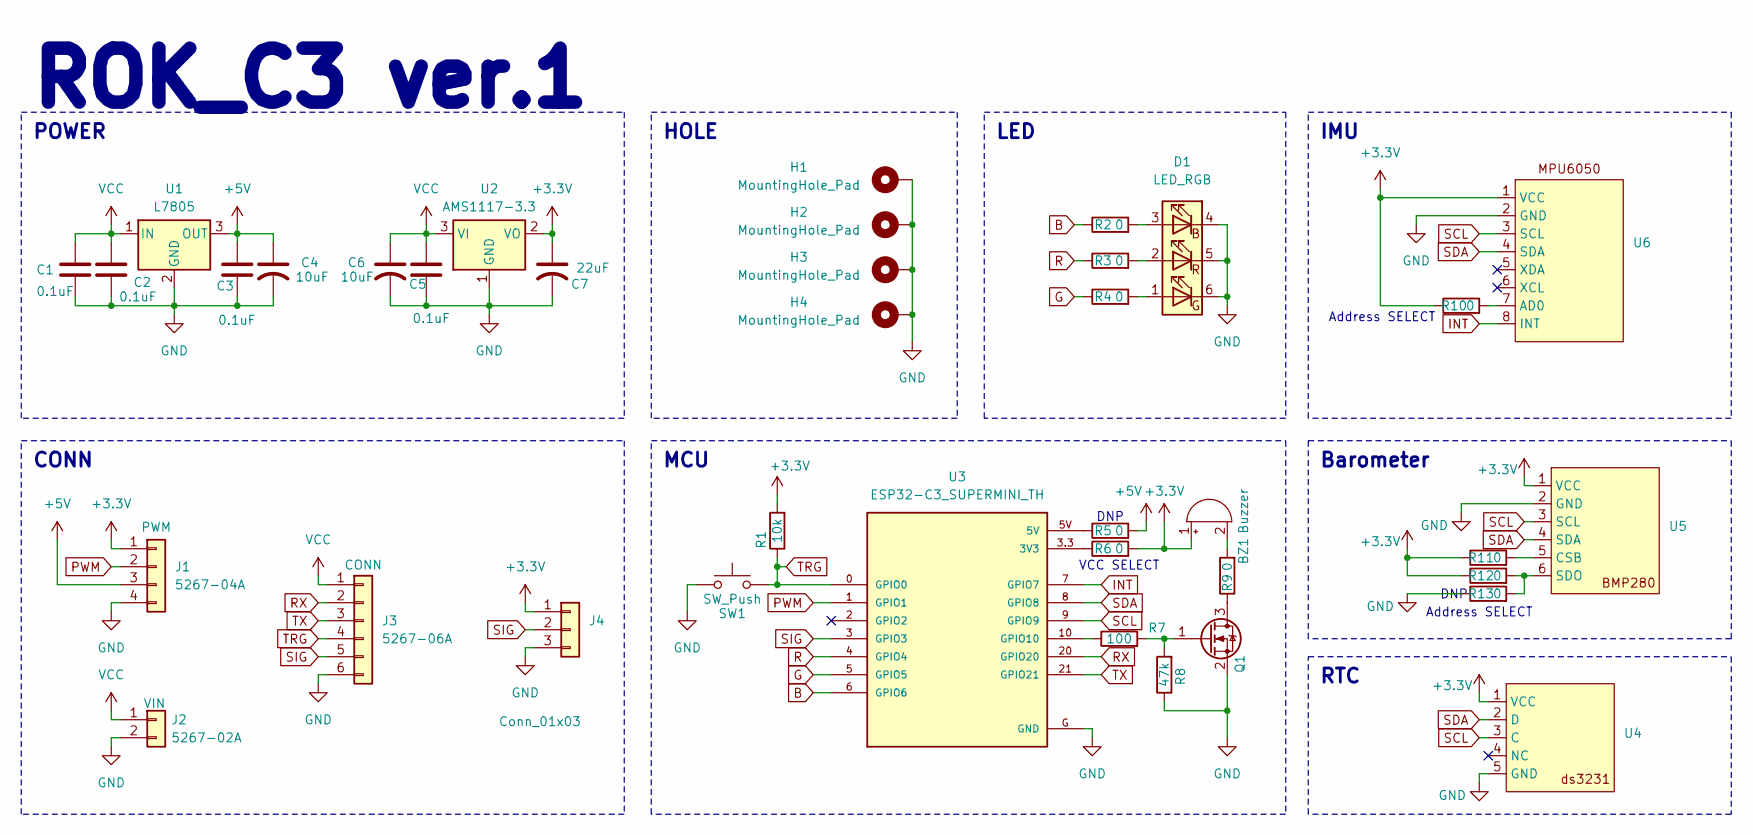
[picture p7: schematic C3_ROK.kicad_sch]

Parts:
BZ1: Buzzer; Buzzer_12x9.5RM7.6
C1, C2, C3, C6: 0.1uF; C_0805_2012Metric_Pad1.18x1.45mm_HandSolder
C4: 10uF; CP_Radial_D6.3mm_P2.50mm
C5: 10uF; CP_Radial_D5.0mm_P2.00mm
C7: 22uF; CP_Radial_D5.0mm_P2.00mm
D1: LED_RGB; LED_RGB_5050-6
H1, H2, H3, H4: MountingHole_Pad; MountingHole_3.2mm_M3_DIN965_Pad
J1: 5267-04A; Molex_SPOX_5267-04A_1x04_P2.50mm_Vertical
J2: 5267-02A; Molex_SPOX_5267-02A_1x02_P2.50mm_Vertical
J3: 5267-06A; Molex_SPOX_5267-06A_1x06_P2.50mm_Vertical
J4: Conn_01x03; Molex_SPOX_5267-03A_1x03_P2.50mm_Vertical
Q1: IRLML2402TR; SOT-23_Handsoldering
R1: 10k; R_0805_2012Metric_Pad1.20x1.40mm_HandSolder
R2, R3, R4, R5, R6, R9, R10, R11, R12, R13: 0; R_0805_2012Metric_Pad1.20x1.40mm_HandSolder
R7: 100; R_0805_2012Metric_Pad1.20x1.40mm_HandSolder
R8: 47k; R_0805_2012Metric_Pad1.20x1.40mm_HandSolder
SW1: SW_Push; SW_PUSH_6mm_H5mm
U1: L7805; TO-220-3_Horizontal_TabDown
U2: AMS1117-3.3; SOT-223-3_TabPin2
U3: ESP32-C3_SUPERMINI_TH; MODULE_ESP32-C3_SUPERMINI_TH
U4: ds3231
U5: BMP280
U6: MPU6050

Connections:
+3.3V: BZ1.1 (+), C7.1, J1.1, J4.1, R1.2, R6.2, R10.1, R11.1, R12.1, U2.2 (VO), U4.1 (VCC), U5.1 (VCC), U6.1 (VCC)
+5V: C3.1, C4.1, J1.3, R5.2, U1.3 (OUT)
B: R2.1, U3.6 (GPIO6)
G: R4.1, U3.5 (GPIO5)
GND: C1.2, C2.2, C3.2, C4.2, C5.2, C6.2, C7.2, D1.4 (RK), D1.5 (GK), D1.6 (BK), H1.1, H2.1, H3.1, H4.1, J1.4, J2.2, J3.6 (Can2_shield), J4.3, Q1.2 (S), R8.1, R13.1, SW1.1, U1.2 (GND), U2.1 (GND), U3.G (GND), U4.5 (GND), U5.2 (GND), U6.2 (GND)
INT: U3.7 (GPIO7), U6.8 (INT)
unnamed: BZ1.2 (-), R9.2
unnamed: D1.1 (BA), R4.2
unnamed: D1.2 (GA), R3.2
unnamed: D1.3 (RA), R2.2
unnamed: Q1.3 (D), R9.1
unnamed: Q1.1 (G), R7.2, R8.2
unnamed: R5.1, U3.5V
unnamed: R6.1, U3.3.3 (3V3)
unnamed: R7.1, U3.10 (GPIO10)
unnamed: R11.2, U5.5 (CSB)
unnamed: R12.2, R13.2, U5.6 (SDO)
unnamed: R10.2, U6.7 (AD0)
PWM: J1.2, U3.1 (GPIO1)
R: R3.1, U3.4 (GPIO4)
RX: J3.2 (Can1_L), U3.20 (GPIO20)
SCL: U3.9 (GPIO9), U4.3 (C), U5.3 (SCL), U6.3 (SCL)
SDA: U3.8 (GPIO8), U4.2 (D), U5.4 (SDA), U6.4 (SDA)
SIG: J3.5 (Can1_shiled), J4.2, U3.3 (GPIO3)
TRG: J3.4 (Can2_L), R1.1, SW1.2, U3.0 (GPIO0)
TX: J3.3 (Can2_H), U3.21 (GPIO21)
VCC: C1.1, C2.1, C5.1, C6.1, J2.1, J3.1 (Can1_H), U1.1 (IN), U2.3 (VI)

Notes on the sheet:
VCC SELECT
Address SELECT
DNP
ROK_C3 ver.1
Barometer
MCU
POWER
LED
RTC
CONN
HOLE
IMU

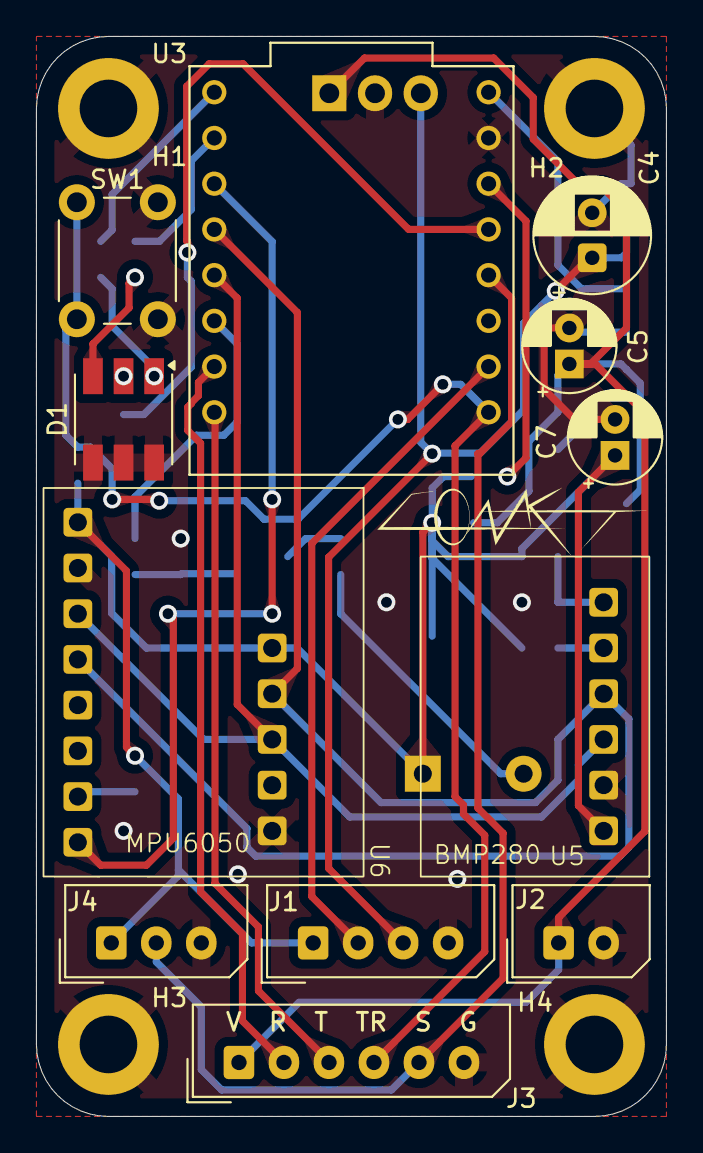
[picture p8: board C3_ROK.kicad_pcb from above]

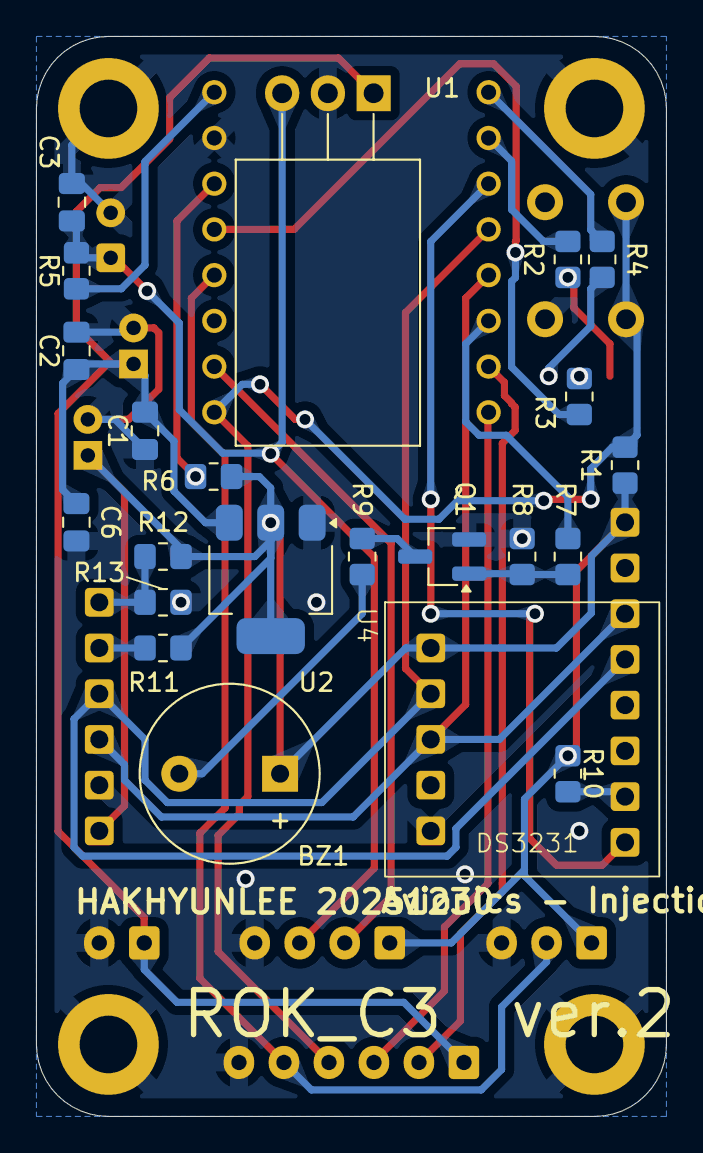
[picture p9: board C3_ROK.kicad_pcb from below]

Board: 2 copper layers, 35.0 x 60.0 mm, 38 parts (22 on the bottom side), 27 nets.

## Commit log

2026-09-11 Replace ROK2 with COMET workspace
    [C3_ROK-B_Cu.gbr, C3_ROK-B_Mask.gbr, C3_ROK-B_Paste.gbr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]
2026-09-11 Document avionics board history
2026-09-11 Document Away_1 dual battery power design
2026-09-11 Select LSM6DSO32XTR as Away_1 main IMU
